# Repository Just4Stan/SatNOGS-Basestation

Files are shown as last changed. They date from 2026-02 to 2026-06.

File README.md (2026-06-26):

# SatNOGS Basestation

Portable, SatNOGS-compatible ground station for the **AetherSpace CubeSat** at 433 MHz.
Built as a joint Master's thesis at KU Leuven (Campus Geel), 2025–2026.

<p align="center">
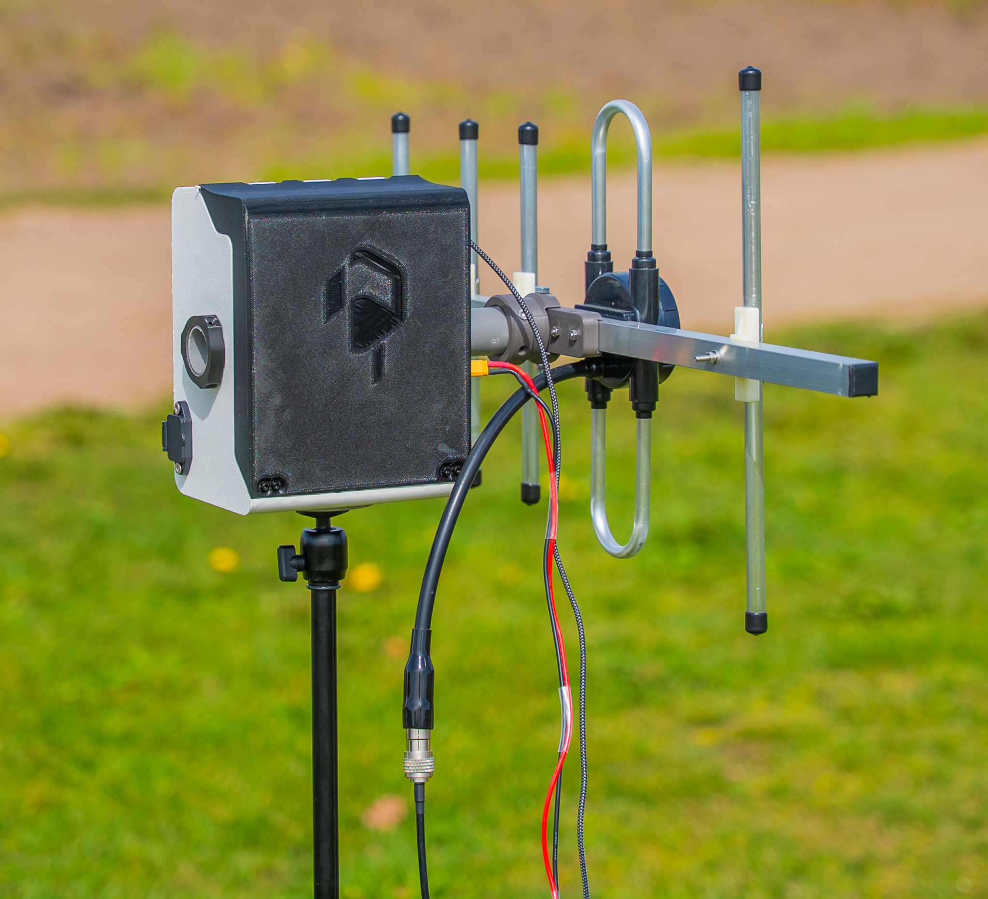
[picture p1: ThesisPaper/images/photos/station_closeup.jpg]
Station head with UHF Yagi
  
</p>
<p align="center">
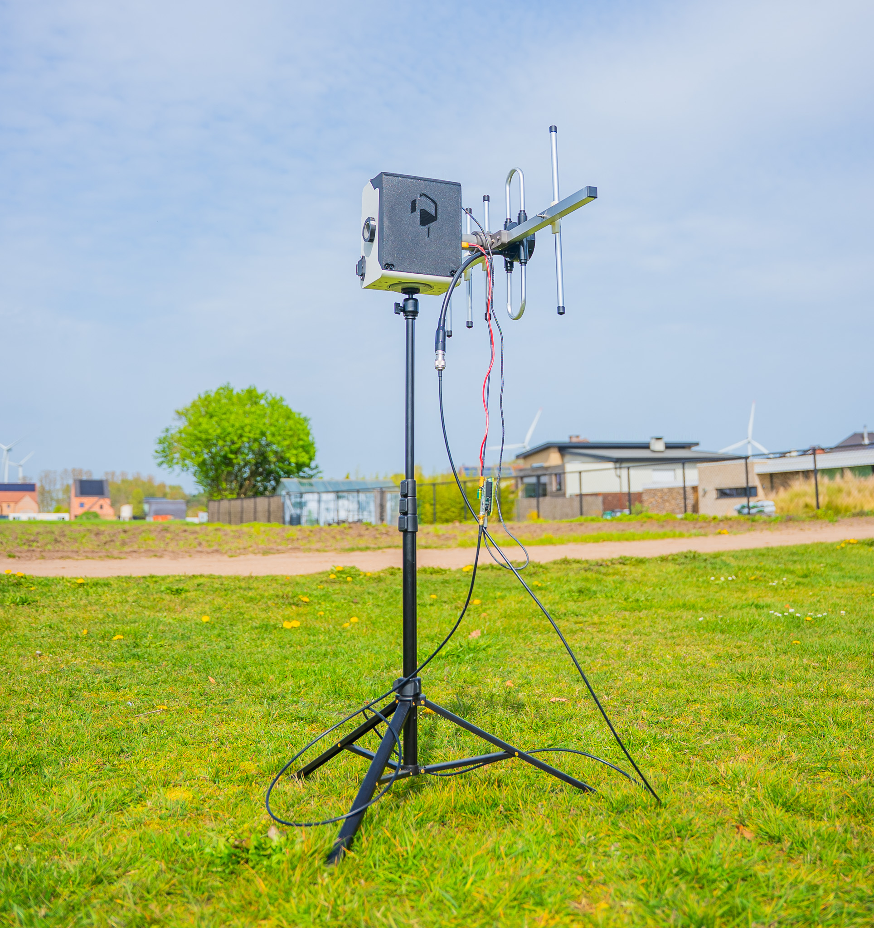
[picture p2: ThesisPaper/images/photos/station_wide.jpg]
Deployed on tripod in the field
  
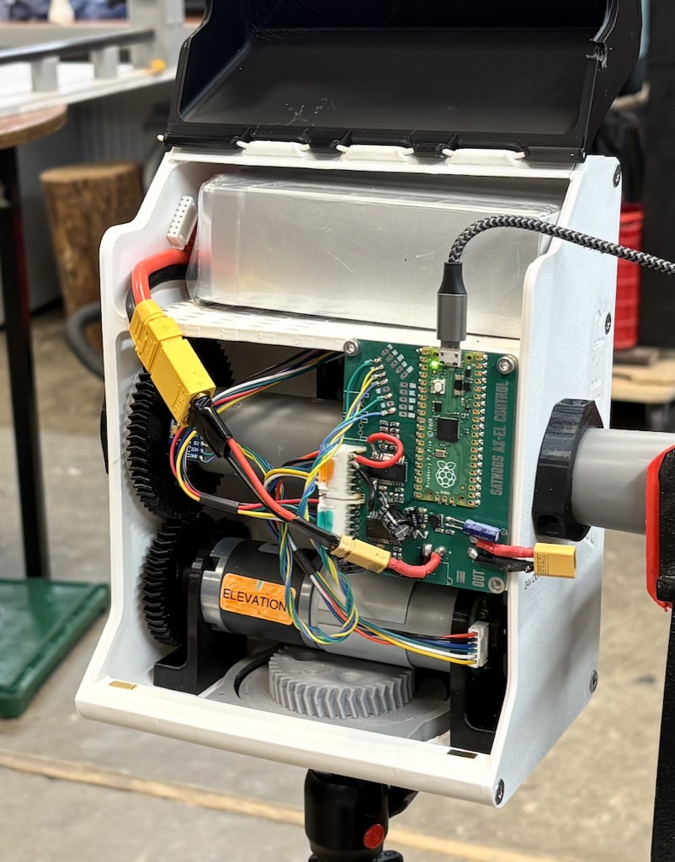
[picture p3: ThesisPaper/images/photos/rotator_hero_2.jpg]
Rotator internals — Pico, motor, herringbone gears
  
</p>

<p align="center">
  <b>3D-printable rotator</b> · <b>1/4"-20 tripod mount</b> · <b>EasyComm / hamlib compatible</b> · <b>phone-configured, no laptop</b>
</p>

---

## What this is (and what it isn't)

This project is a **deliberate alternative** to the canonical SatNOGS receive stack. A fully capable SatNOGS ground station can be built with a Raspberry Pi 3, the official `satnogs-client`, an RTL-SDR dongle, and any hamlib-compatible rotator — and for receiving arbitrary amateur satellites that is the right choice. We built this station instead because:

1. **AetherSpace-specific.** The AetherSpace CubeSat carries a TI CC1200 transceiver. Using the same CC1200 on the ground guarantees modulation-format compatibility and avoids the software-demodulator complexity of matching a CubeSat's exact FSK parameters in GNU Radio.
2. **Educationally interesting.** The build spans mechanical design (3D-printed rotator, printed ball bearings, herringbone gears), PCB design (dual-RP2040 + CC1200 HAT), embedded firmware (EasyComm III, PID, encoder ISRs, COBS protocol, PIO-based AX.25 G3RUH decoder), Pi-side software (pass prediction, Doppler, phone-first HTTPS dashboard), and protocol integration (SiDS to the SatNOGS DB). An SDR-based station would skip most of that.
3. **Portable and self-contained.** Deploys in minutes on a tripod, configured from a phone — no laptop, no SSH. This is harder with the GNU Radio-based `satnogs-client` which expects a persistent host.

If you want a general-purpose SatNOGS station today, run **`satnogs-client` + RTL-SDR on a Pi 3B+** with any EasyComm-speaking rotator (including this one). If you want to track AetherSpace or learn how a ground station is built end-to-end, use this.

---

## System overview

<p align="center">
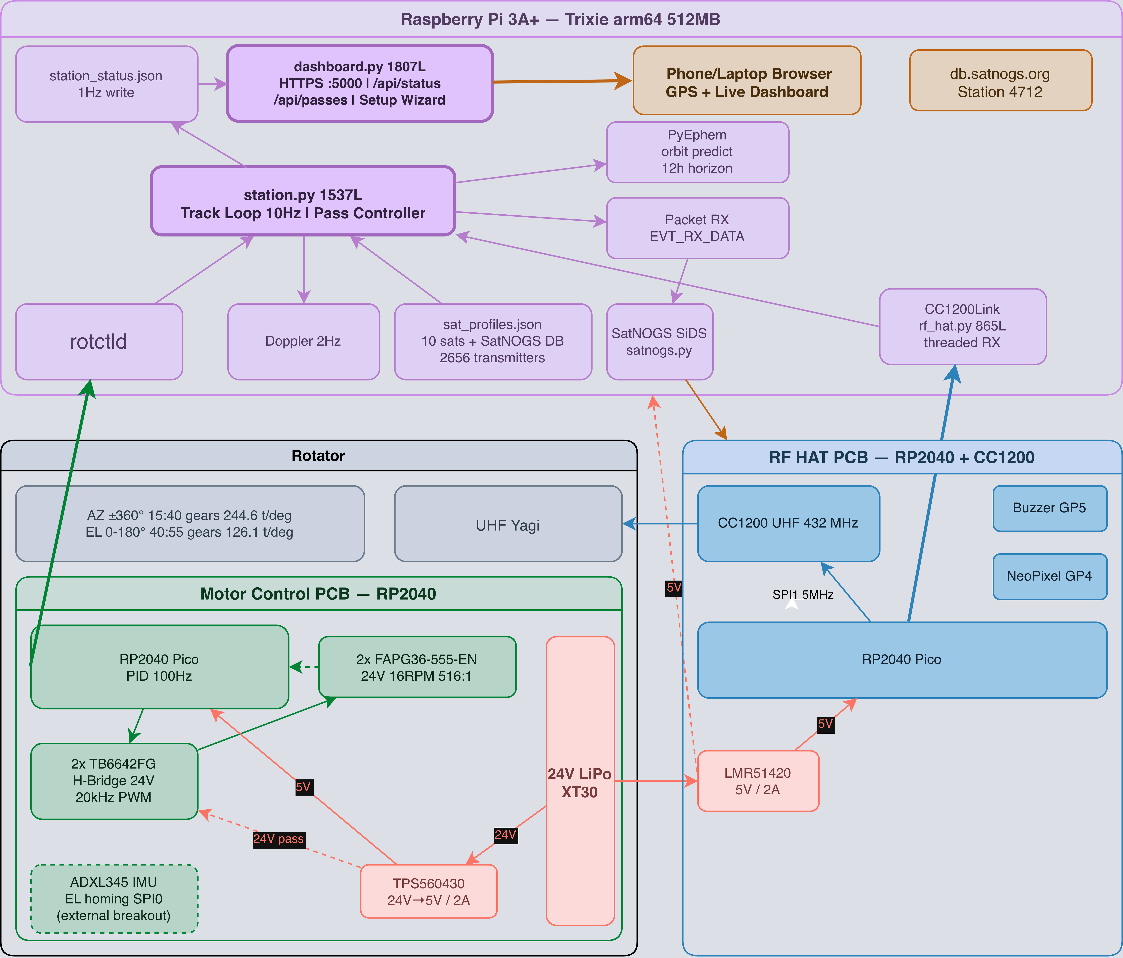
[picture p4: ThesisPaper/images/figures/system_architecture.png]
System architecture: Pi 3A+ driving the motor-control PCB and CC1200 RF HAT
  
</p>

> **v1** (above) is the field-validated configuration — two separate boards, USB for the rotator, UART for the RF HAT.
> **v2** (`MOTOR_RF_HAT/`) is the design-complete successor — one Pi HAT, A4950 motor drivers, 100 Ω GPIO series resistors on the driver lines. Routed and BOM-finalised; not yet fabricated.

---

## Repository structure

| Path | Contents |
|---|---|
| [`Firmware/rp2040-satnogs-rotator/`](Firmware/rp2040-satnogs-rotator/) | Rotator Pico firmware — EasyComm III, 100 Hz PID, IMU-based EL homing, runaway detection, watchdog |
| [`Firmware/rp2040-rf-hat/`](Firmware/rp2040-rf-hat/) | RF HAT Pico firmware — COBS/CRC-16 protocol, dual CC1200 SPI driver, PIO serial-mode RX + AX.25 G3RUH decoder |
| [`MotorPCB/`](MotorPCB/) | v1 KiCad 9 rotator controller PCB (13 hierarchical sub-sheets). Field-deployed. |
| [`RF_HAT/`](RF_HAT/) | v1 dual-CC1200 Pi HAT (source: `rf_hat_circuit.py` → generates `RF_HAT_out/`). Field-deployed. |
| [`MOTOR_RF_HAT/`](MOTOR_RF_HAT/) | v2 combined motor-control + RF HAT (design-complete, routed, ready to order). Thesis-final hardware. |
| [`Pi/`](Pi/) | Python station stack: `station.py`, `dashboard.py`, `rf_hat.py`, `sat_library.py`, decoders, systemd services, SmartRF configs |
| [`Hardware/`](Hardware/) | Motor + driver datasheets (FAPG36-555-EN, TB6642FG) |
| [`ThesisPaper/images/`](ThesisPaper/images/) | All thesis visuals: `figures/` (plots), `figures/evidence/` (reception evidence plots), `photos/` (hardware + CAD) — consumed by LaTeX `\graphicspath{./images/}` |
| [`ThesisPaper/`](ThesisPaper/) | LaTeX thesis (KU Leuven FIIW template) + rendered figures |
| [`tools/`](tools/) | Analysis utilities (`analyze_passes.py` — generates the reception-evidence report) |
| [`RF_Devboard/`](RF_Devboard/) | CC1200 RF dev board (predecessor to the HAT): Altium PCB, Pico SDK driver, PC test GUI |
| [`docs/`](docs/) | System architecture diagram (`.drawio` + HTML render) |
| `captures/` | Raw RF captures per pass (gitignored — kept on disk only) |
| `Papers/` | Reference material including Hanssens (2023) baseline thesis (gitignored) |

| Firmware artifact (at repo root) | Built by |
|---|---|
| `firmware.uf2` | `Firmware/rp2040-satnogs-rotator/` (v1 rotator) |
| `rf_hat_firmware.uf2` | `Firmware/rp2040-rf-hat/` (v1 RF HAT) |
| `motor_rf_hat_firmware.uf2` | `Firmware/rp2040-motor-rf-hat/` (v2 combined) |

---

## Hardware

<p align="center">
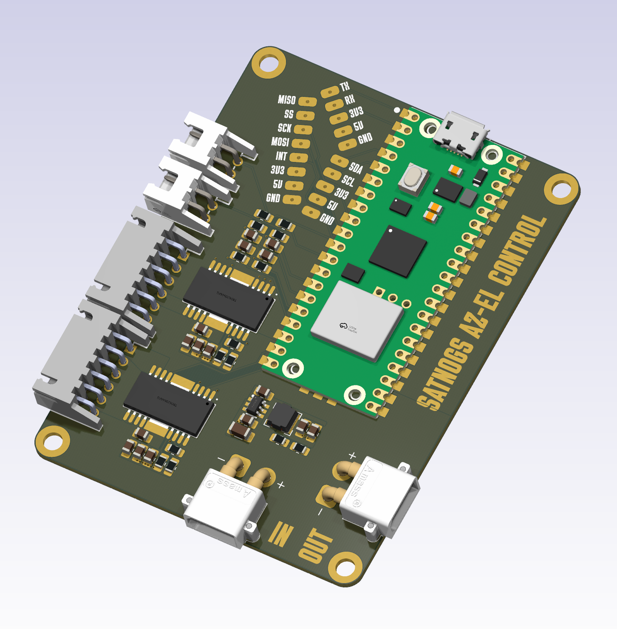
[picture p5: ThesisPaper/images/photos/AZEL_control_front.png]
v1 motor-control PCB
  
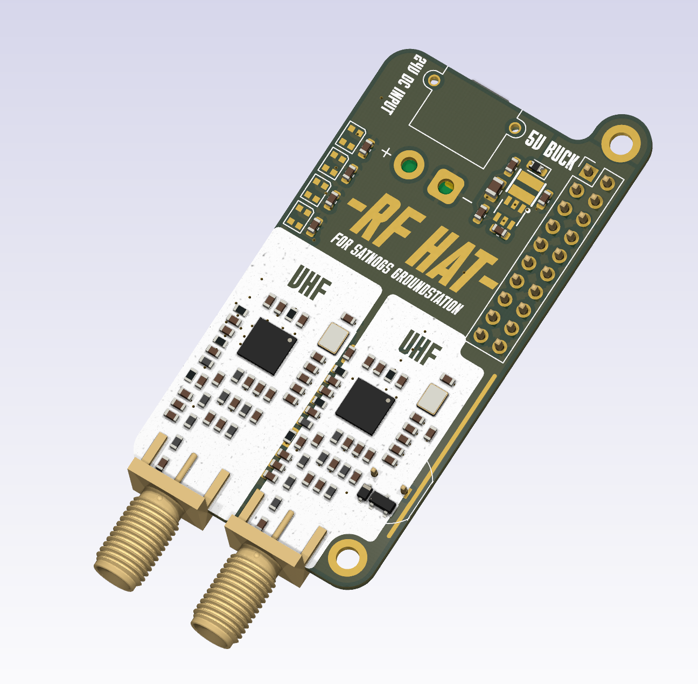
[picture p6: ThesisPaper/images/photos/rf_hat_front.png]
v1 dual-CC1200 RF HAT
  
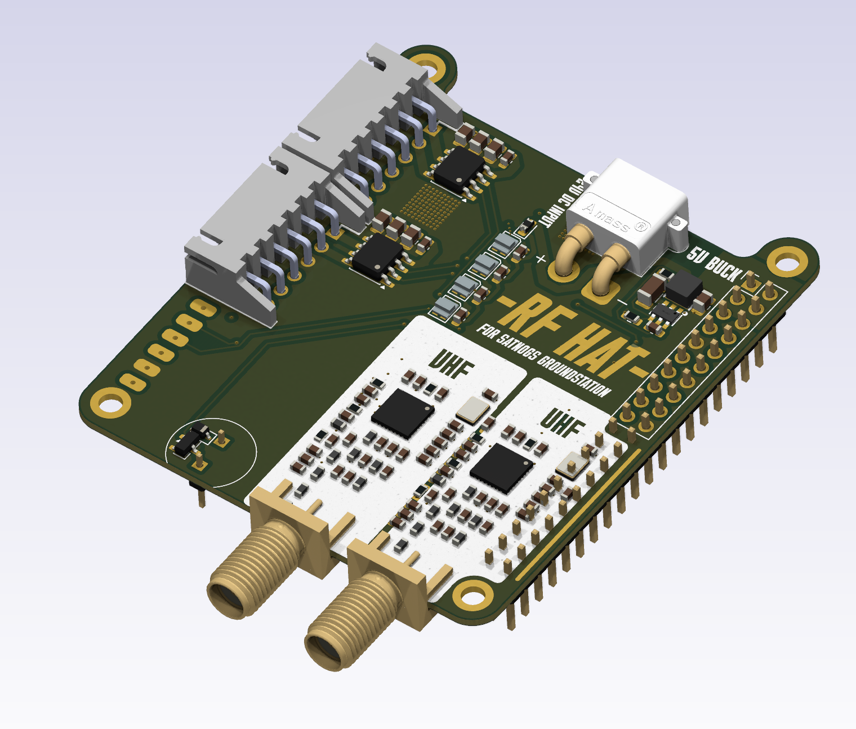
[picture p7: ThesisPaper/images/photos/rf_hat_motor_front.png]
v2 combined MOTOR_RF_HAT
  
</p>
<p align="center"><sub>Left to right: v1 motor-control PCB · v1 dual-CC1200 RF HAT · v2 combined MOTOR_RF_HAT (design-complete)</sub></p>

| Component | Details |
|---|---|
| **MCU** | RP2040 (Raspberry Pi Pico), one per board (v1); single RP2040 on v2 |
| **Motor driver (v1)** | 2× TB6642FG full-bridge (24 V, 20 kHz PWM) |
| **Motor driver (v2)** | 2× A4950 (standard, in-stock; replaces scarce TB6642FG) |
| **Motors** | FAPG36-555-EN, 24 V, 16 RPM, 516:1 internal planetary gearbox |
| **Encoders** | 2-channel Hall (64 edges/rev, 4× quadrature) |
| **IMU** | ADXL345 3-axis accelerometer (EL auto-homing at boot) |
| **RF** | 2× TI CC1200 on 6-layer Pi HAT — UHF (432 MHz) populated, VHF (144 MHz) routed only |
| **Antenna** | Siretta Oscar 44 Yagi, 434 MHz, ~9 dBi (used in field testing) over 3 m RG-58 |
| **Station computer** | Raspberry Pi 3 Model A+, Debian 13 (Trixie), armhf 32-bit |

### Axis gearing

| Axis | External ratio | Total ratio | Ticks/degree | Travel |
|---|---|---|---|---|
| Azimuth | 15:40 (2.667:1) | 1376:1 | 244.6 | ±360° |
| Elevation | 40:55 (1.375:1) | 709.5:1 | 126.1 | 0–180° |

No slip ring — AZ rewinds between passes via `PARK`. Shortest-path wrapping handles north crossings automatically.

### Mechanical design

<p align="center">
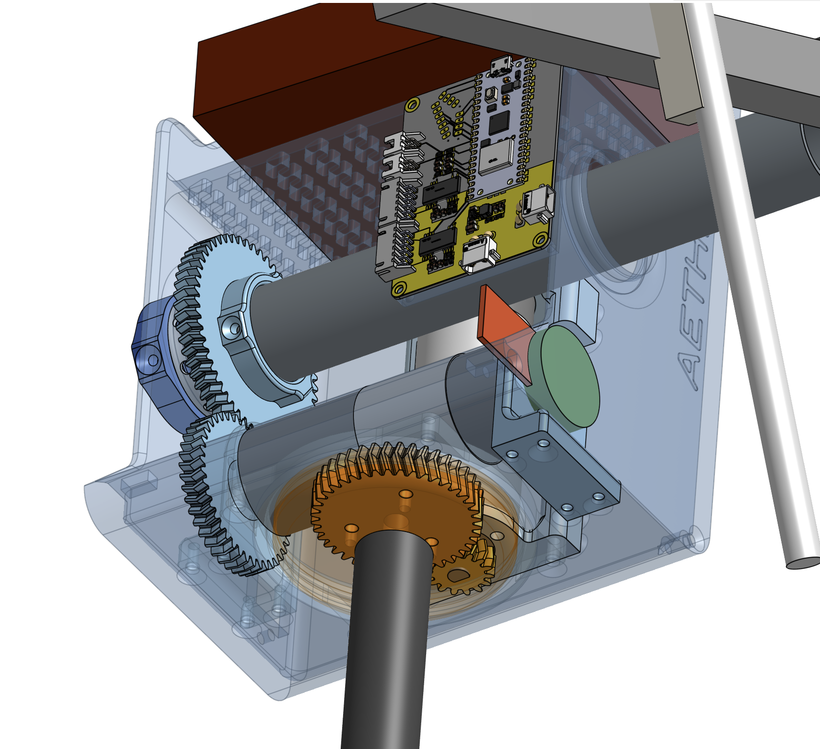
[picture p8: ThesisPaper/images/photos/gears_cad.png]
EL-axis CAD cutaway: herringbone gear train and Pico
  
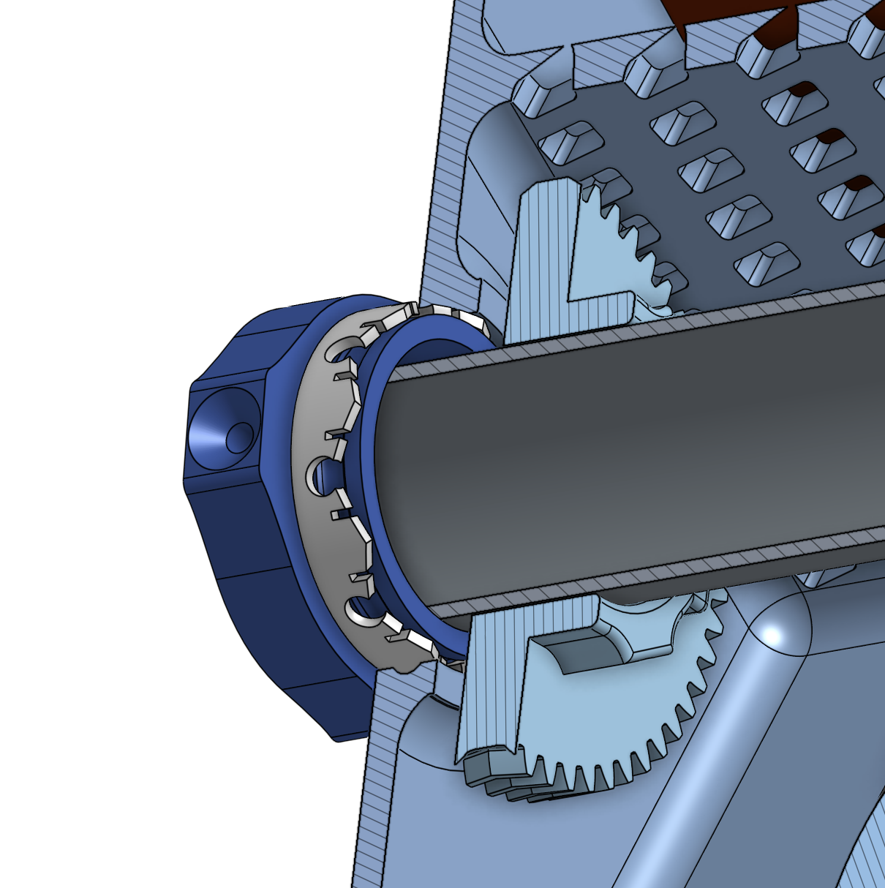
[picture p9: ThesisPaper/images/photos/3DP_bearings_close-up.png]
Printed deep-groove ball bearing
  
</p>

Fully 3D-printable in ASA (UV-resistant, Tg ≈ 100 °C). All structural parts fit a 220×220 mm build plate. Printed deep-groove ball bearings on both axes (3 mm steel balls, integrated races, press-in retainer). Double-helical (herringbone) gears, 15° helix, 1.333 mm normal module, 8 mm face width. Standard **1/4"-20 UNC tripod thread** on the base.

[View CAD on Onshape](https://cad.onshape.com/documents/a73149deb7dec0be4e4b4c14/w/e82e548d7d93085f89291bd5/e/c3e50364326e22d368cc64e2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)

---

## LNA recommendation (RX sensitivity)

Field testing without an external LNA produced **no protocol-valid frame decodes** — the link budget (`ThesisPaper/draft_link_budget.md`) shows the measured system noise floor sits roughly 20 dB above thermal, and the AetherSpace 14 dBm / 2 dBi downlink has insufficient margin at ~600 km range in that configuration. Adding an LNA is the single highest-impact upgrade.

**Recommended path — mast-mounted LNA + bias-T:**

| Part | Role | Notes |
|---|---|---|
| **Qorvo SPF5189Z** (or pre-built module, e.g. Nooelec SAWbird+ 433) | Primary LNA | NF 0.6 dB, ~20 dB gain at 433 MHz, SOT-89, +5 V, community standard for 433 MHz amateur RX |
| **Mini-Circuits PGA-103+** | Alternative | NF 0.5 dB, 21 dB gain, SMA module, more expensive |
| **EPCOS B39431B3710U410** (or equivalent) | 433.92 MHz SAW filter, pre-LNA | Rejects out-of-band interferers; improves linearity |
| Bias-T (on-PCB) | Feeds DC up the coax to power mast LNA | ~120 nH choke + DC-block capacitor + feedthrough |

**Why mast-mounted is preferred over PCB-integrated (Friis cascade):** the first stage's noise figure dominates the whole chain. Placing the LNA at the antenna bypasses ~0.6 dB of RG-58 loss *before* amplification, and avoids lifting board-level digital noise (RP2040, LMR51420 buck harmonics, Pi HDMI) into the RX path. A PCB-integrated LNA helps less for the same cost.

**TI CC1190 is not applicable here:** it is TI's companion range-extender for CCxxxx transceivers, but only covers 850–950 MHz. There is no TI-supplied LNA companion for CC1200 in the 410–475 MHz band, so an external discrete or module-based LNA is required.

The v2 MOTOR_RF_HAT should include a bias-T network on the UHF antenna port to make mast-LNA operation plug-and-play.

---

## Quick start

```sh
# Build rotator firmware
cd Firmware/rp2040-satnogs-rotator
pip install platformio
pio run
```

Flash: hold **BOOTSEL**, plug USB, copy `firmware.uf2` to the **RPI-RP2** drive.

Connect at 115200 baud (`pio device monitor` or any serial terminal):

```
AZ90.0 EL45.0    → move to position
AZ               → query current AZ/EL
STOP             → halt motors
PARK             → return to (0, 0)
VE               → firmware version
HELP             → list all commands
```

Full command reference and PID tuning: [`Firmware/rp2040-satnogs-rotator/README.md`](Firmware/rp2040-satnogs-rotator/README.md).

---

## SatNOGS integration

The rotator speaks **EasyComm III (hamlib model 204)** on the rotator path, so the Pi runs stock `rotctld` with no custom software. `rotctld.service` in [`Pi/services/`](Pi/services/) is the auto-start unit.

```sh
# rotctld exposes the rotator on TCP 4533
echo "p"             | nc <pi-ip> 4533   # query position
echo "P 90.0 30.0"   | nc <pi-ip> 4533   # command AZ 90, EL 30
```

### Satellite tracking

`Pi/station.py` predicts passes from CelesTrak TLEs via PyEphem, drives `rotctld` at 10 Hz, configures the CC1200 per satellite, applies Doppler correction at 2 Hz, and logs pass CSVs with 5 Hz telemetry.

```sh
cd ~/SatNOGS-Basestation/Pi
python3 station.py --list              # list upcoming passes
python3 station.py --sat "ISS"         # track a named satellite
python3 station.py --daemon            # auto-track all passes (no SSH)
```

See [`Pi/README.md`](Pi/README.md) for daemon mode, scan mode, and dashboard operation.

### SatNOGS DB (SiDS) vs `satnogs-client`

Decoded frames are submitted directly to `db.satnogs.org/api/telemetry/` via the SiDS (Simple Downlink Sharing) protocol. Station **4712 "Aether-Basestation"** is registered on the network; it will appear *offline* on the network map because we do not poll `/api/jobs/` — `satnogs-client`'s GNU Radio + SoapySDR pipeline is SDR-centric and incompatible with the CC1200 hardware packet modem.

**If you want the standard SatNOGS experience on top of this rotator:** install `satnogs-client` with any RTL-SDR dongle, set `SATNOGS_ROT_MODEL=ROT_MODEL_NETROTCTL` and `SATNOGS_ROT_PORT=localhost:4533`. The `RfBackend` abstraction in [`Pi/rf_backend.py`](Pi/rf_backend.py) also supports an RTL-SDR as a parallel path alongside the CC1200.

---

## Motion control

The rotator runs a 100 Hz PID loop per axis (Kp 0.15, Ki 0.03, Kd 0.02, 0.05° deadband, 95 % duty cap). The integral and derivative terms trade overshoot against settling time:

<p align="center">
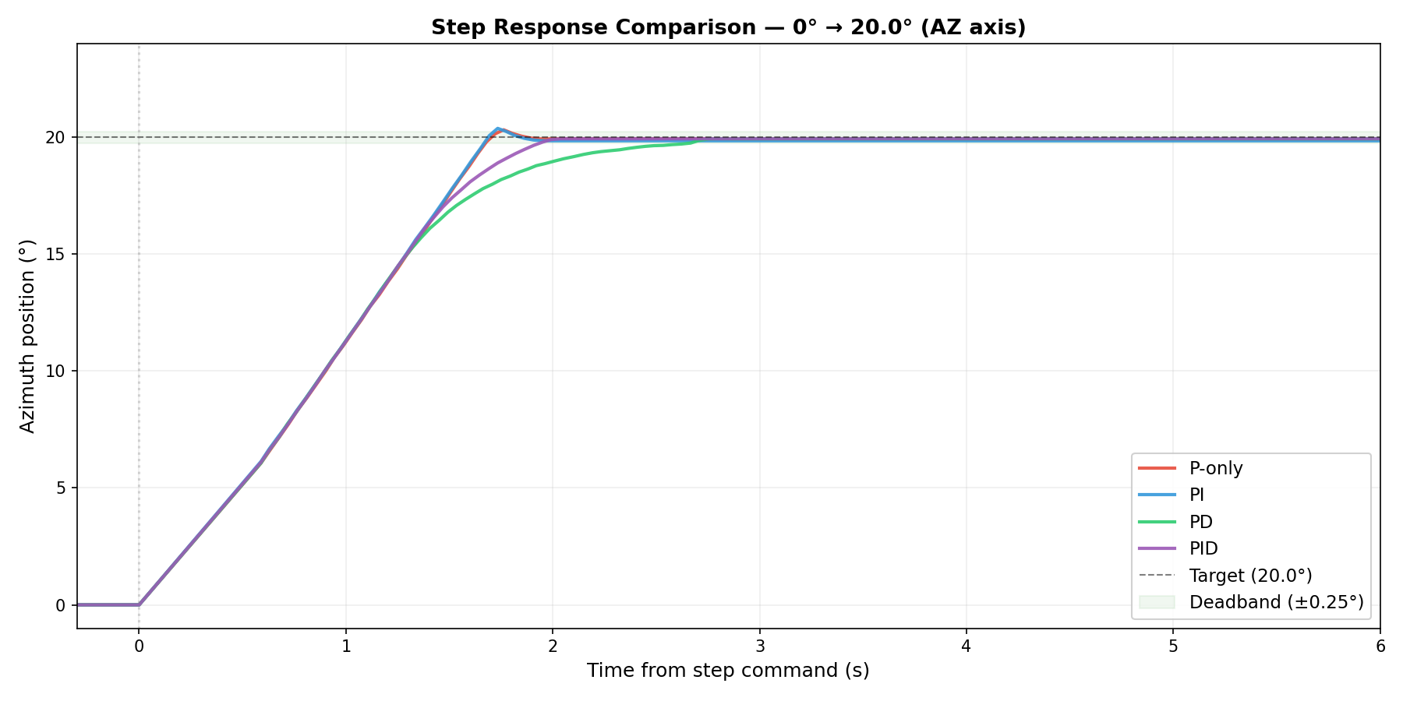
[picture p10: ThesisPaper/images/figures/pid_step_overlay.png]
AZ-axis step response: P, PI, PD and PID compared
  
</p>

---

## Safety features

- **Runaway detection** — emergency stop if position exceeds soft limits by 50° (catches PID positive-feedback failures like the EL-inversion bug found during bring-up)
- **Soft limits** — AZ clamped to ±360°, EL clamped to 0–180°
- **Duty capping** — 95 % max PWM, avoids TB6642FG/A4950 over-current on motor stall
- **IMU-based EL homing** — drives EL to horizontal via ADXL345 gravity vector at boot
- **Shortest-path AZ wrapping** — 350°→10° takes the 20° path, not 340°; encoder re-centres after settling near ±360°
- **8 s hardware watchdog** — both Picos; includes homing loop
- **Driver fault lines** — TB6642FG ALERT pins wired to the RP2040 (currently bypassed in firmware; enable for v2)

---

## Design philosophy

- **Economical.** v2 rotator BOM (controller board + motors + mechanics) ≈ €75; ≈ €100 including the Pi.
- **Reproducible.** 3D-printable rotator on a consumer FDM printer, standard 1/4"-20 tripod, LCSC-basic components where possible.
- **Stock-protocol.** EasyComm + hamlib on the rotator; SiDS on the DB side. No proprietary glue.
- **Open source.** Hardware CERN-OHL-S, firmware and software MIT.

---

## Further reading

- [`ThesisPaper/`](ThesisPaper/) — full LaTeX thesis (KU Leuven FIIW template) and figures.
- [`ThesisPaper/draft_link_budget.md`](ThesisPaper/draft_link_budget.md) — link-budget analysis with LNA impact.
- [`docs/system_architecture.drawio`](docs/system_architecture.drawio) — editable system diagram (`docs/system_diagram.html` renders it).
- Per-board READMEs under [`Firmware/`](Firmware/), [`Pi/`](Pi/), [`MotorPCB/`](MotorPCB/), [`RF_HAT/`](RF_HAT/), and [`MOTOR_RF_HAT/`](MOTOR_RF_HAT/).

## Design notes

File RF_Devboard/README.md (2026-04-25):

# CC1200RXFrontend

Firmware for an RP2040-based CC1200 “RF frontend” that controls a TI **CC1200** sub-GHz transceiver and exposes a **binary protocol over USB CDC**. The intended use case is a **SatNOGS groundstation** host that configures the CC1200, switches RX/TX state, monitors metrics, ingests received bytes (either polled or streamed), and can perform basic **TX test transmissions**.

Key features:
- USB CDC **binary protocol** (COBS framing + CRC16) for control, telemetry, optional RX streaming, and basic TX commands
- CC1200 SPI driver supporting normal + extended registers, FIFO reads/writes, and command strobes
- Host reference implementation and GUI in `PC_test/cc1200_gui.py` (includes a **Send Hex** TX test)
- RP2040 LED status indication

> Critical constraint: USB CDC stdio is used for the binary protocol. Printing debug text over the same interface will corrupt the stream.

---

## Repository layout

- `src/main.c`  
  System init, CC1200 bring-up, protocol polling loop.

- `src/usb_proto.[ch]`  
  Binary protocol framing/parsing and command dispatch. Handles RX streaming, metrics collection, and TX FIFO / TX start commands.

- `src/usb_cobs.[ch]`  
  COBS encoder/decoder used by the transport.

- `src/crc16.[ch]`  
  CRC-16/CCITT-FALSE implementation used by the transport.

- `src/config.h`  
  RP2040 pin mapping + SPI configuration.

- `src/leds.[ch]`  
  RGB status LED control and heartbeat.

- `CC1200_driver/cc1200.[ch]`  
  CC1200 low-level driver: register access, FIFO access, strobes.

- `CC1200_driver/cc1200_hal.[ch]`  
  Pico SDK SPI/GPIO HAL for CC1200. Includes SO(MISO)-ready wait on CS assert.

- `src/cc1200_profile.c`  
  Helper for applying a prepared list of register writes.

- `PC_test/cc1200_gui.py`  
  Reference host-side implementation and GUI (serial framing/parsing, SmartRF export parsing, register I/O, state control, RX ingest, **TX “Send Hex” test**).

---

## Hardware assumptions

### Default RP2040 pin mapping

Defined in `src/config.h`:

**LEDs**
- `GPIO12` : Blue
- `GPIO13` : Green
- `GPIO14` : Red
- `GPIO15` : Extra / heartbeat

**CC1200 (SPI0)**
- `GPIO18` : SCK
- `GPIO19` : MOSI
- `GPIO20` : MISO (also used for SO-ready)
- `GPIO21` : CSN
- `GPIO22` : CC1200 GPIO0
- `GPIO23` : CC1200 GPIO2
- `GPIO24` : CC1200 GPIO3
- `GPIO25` : CC1200 RESET

SPI frequency defaults to **5 MHz**. SO-ready timeout defaults to **5000 µs**.

### SPI mode and SO-ready behavior

- SPI is configured for **Mode 0**, 8-bit, MSB-first.
- On CSN assert (low), the HAL waits for CC1200 **SO (wired to MISO)** to go low, with a timeout. If SO does not go ready, the transfer is aborted.

---

## Firmware lifecycle

At boot:
1. Initializes USB CDC stdio and LEDs.
2. Initializes CC1200 HAL (SPI + GPIO) from `config.h`.
3. Resets CC1200 and verifies communication.
4. Optionally reads CC1200 identification fields (part/version) to validate the transceiver.
5. Enters a polling loop:
   - toggles heartbeat
   - processes incoming USB frames and emits responses/events
   - (optionally) drains RX FIFO and emits RX streaming events
   - sleeps briefly

---

## USB CDC binary protocol

### Transport framing

Frames are transmitted as:
- `COBS(payload) + 0x00` delimiter

Payload layout (little-endian where applicable):
- `type`  : `u8`
- `seq`   : `u8`
- `len`   : `u16` length of `body`
- `body`  : `len` bytes
- `crc16` : `u16` CRC-16/CCITT-FALSE computed over `type..body` (header + body, excluding delimiter)

CRC parameters:
- Polynomial: `0x1021`
- Init: `0xFFFF`
- XOROUT: `0x0000`
- RefIn/RefOut: false (CCITT-FALSE)

### Message types

#### Control / status
- `0x01` `MSG_PING`
- `0x02` `MSG_GET_INFO`
- `0x03` `MSG_SET_STATE`
  - `STATE_IDLE = 0`
  - `STATE_RX   = 1`
  - `STATE_TX   = 2` *(TX strobe; mainly useful for quick testing)*
- `0x04` `MSG_SET_STREAMING` (enable/disable async RX events)
- `0x05` `MSG_GET_METRICS`

#### Register I/O
- `0x10` `MSG_READ_REG`
- `0x11` `MSG_WRITE_REG`
- `0x12` `MSG_READ_EXT`
- `0x13` `MSG_WRITE_EXT`

#### FIFO / strobes
- `0x20` `MSG_RX_READ` (pull-mode RX FIFO read)
- `0x21` `MSG_STROBE`

#### TX (FIFO + transmit)
These commands provide a minimal TX path suitable for basic test transmissions. Actual on-air formatting depends on the active CC1200 packet configuration (SmartRF profile).

- `0x24` `MSG_TX_FLUSH`  
  Flush TX FIFO (`SFTX`).

  Request body: *(empty)*  
  Response body:
  - `ok` : `u8` (1 on success)

- `0x22` `MSG_TX_WRITE`  
  Write bytes into TX FIFO.

  Request body:
  - `flags` : `u8`
    - bit0: flush TX FIFO before writing (`SFTX`)
    - bit1: force IDLE before touching TX path (`SIDLE`)
  - `count` : `u8`
  - `data`  : `count` bytes

  Response body:
  - `ok`      : `u8` (1 on success)
  - `written` : `u8` (bytes written)

- `0x23` `MSG_TX_SEND`  
  Trigger transmit (`STX`) after data is staged in TX FIFO.

  Request body:
  - `flags` : `u8` *(optional; if omitted, defaults to 0)*
    - bit0: strobe `SIDLE` after `STX`
    - bit1: strobe `SRX` after `STX` (RX wins if both bit0+bit1 set)
    - bit2: flush TX FIFO before `STX` (`SFTX`) *(mostly useful for “empty send” sanity tests)*

  Response body:
  - `ok` : `u8` (1 on success)

> Note: These TX commands are “raw FIFO + STX”. If your profile uses the CC1200 packet engine with a length byte, CRC, whitening, etc., the bytes you write must match what the configured packet engine expects.

#### Profile staging (bulk apply)
- `0x30` `MSG_PROFILE_CLEAR`
- `0x31` `MSG_PROFILE_BEGIN`
- `0x32` `MSG_PROFILE_CHUNK`
- `0x33` `MSG_PROFILE_APPLY`

#### Responses and events
- Responses set `type |= 0x80` (response flag) and mirror the request `seq`.
- Async events:
  - `0xE0` `EVT_RX_DATA`
  - `0xE1` `EVT_ERROR`
  Async events typically use `seq = 0`.

### Error handling

- Malformed frames and CRC failures emit `EVT_ERROR`.
- Command-level errors (invalid args, SPI failures, bounds issues, overflow conditions) also emit `EVT_ERROR`.

---

## CC1200 control and data path

### Driver capabilities

The CC1200 driver supports:
- Normal register read/write
- Burst access
- Extended register access via the CC1200 “extended address” mechanism
- RX/TX FIFO burst reads/writes
- Command strobes (e.g., `SIDLE`, `SRX`, `SFRX`, `SFTX`, `STX`)

### RX streaming (push mode)

When streaming is enabled with `MSG_SET_STREAMING`:
- Firmware polls the CC1200 RX FIFO byte count and drains available bytes in chunks (up to 64 bytes per event).
- Each chunk is emitted as `EVT_RX_DATA`.

`EVT_RX_DATA` body format:
- `count` : `u8`
- `data`  : `count` bytes

This is the preferred ingestion mode for a groundstation pipeline that continuously forwards RX bytes to a demod/decoder stage.

### Pull-mode RX FIFO read

`MSG_RX_READ` requests a read of up to `max_bytes` from RX FIFO and returns:

Response body:
- `count` : `u8`
- `data`  : `count` bytes

### TX test path (raw FIFO + STX)

A basic TX sequence is:
1. `MSG_TX_FLUSH` *(optional but recommended for tests)*
2. `MSG_TX_WRITE` with `flags.bit0=1` to flush and `flags.bit1=1` to force `SIDLE`
3. `MSG_TX_SEND` to strobe `STX` (optionally return to `IDLE` or `RX` after)

The reference GUI includes a **TX Test (Send Hex)** panel that performs exactly this sequence.

---

## Metrics

`MSG_GET_METRICS` reads CC1200 status values and returns a compact metrics block, including:
- MARC state
- RX FIFO byte count
- RSSI (reconstructed from CC1200 RSSI registers)

Returned body (current format):
- `marc`        : `u8`
- `rxbytes`     : `u8` (masked to 7 bits by firmware)
- `rssi_raw_1db`: `i8` (coarse display value)
- `rssi_dbm_x10`: `i16` (dBm * 10, little-endian; `-32768` indicates invalid)

The Python GUI supports both legacy (short) and current (extended) metrics response formats.

---

## Profile configuration (SmartRF exports)

Two mechanisms exist:

1. **Direct register writes**  
   The host writes registers (normal and extended) one-by-one using `MSG_WRITE_REG` / `MSG_WRITE_EXT`.
   This is implemented in the reference GUI and is straightforward but more transaction-heavy.

2. **Bulk staging and apply** (recommended for SatNOGS integration)  
   The host stages register operations in RAM and applies them in one commit:
   - `MSG_PROFILE_CLEAR` clears staged entries
   - `MSG_PROFILE_BEGIN` starts a staging session (optional expected count)
   - `MSG_PROFILE_CHUNK` appends entries
   - `MSG_PROFILE_APPLY` writes all staged entries (firmware strobes `SIDLE` first)

`MSG_PROFILE_CHUNK` body format:
- `count` : `u8`
- Repeated `count` times:
  - `type` : `u8` (bit0 = 1 means extended register write, 0 means normal)
  - `addr` : `u8`
  - `val`  : `u8`

`MSG_PROFILE_APPLY` may accept an apply-flags byte to strobe after writing:
- bit0: strobe `SRX`
- bit1: strobe `SIDLE`
- bit2: strobe `SFRX`
- bit3: strobe `SFTX`

---

## Building (Pico SDK)

### Dependencies
- Raspberry Pi Pico SDK (PICO_SDK_PATH must be set)
- CMake
- Ninja (optional but used by example)

### Example build (Windows)

```bat
cd C:\pico\satnogs_rx_frontend
rmdir /s /q build
mkdir build
cd build

set PICO_SDK_PATH=C:\pico\pico-sdk

cmake -G "Ninja" ..
cmake --build .

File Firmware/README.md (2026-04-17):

# Firmware — SatNOGS Ground Station Software System

Two RP2040 Pico microcontrollers, controlled by a single Raspberry Pi 3 Model A+,
form the ground station electronics:

```
                          ┌─────────────────────────────────────────────────────┐
                          │  Raspberry Pi 3 Model A+                            │
                          │  (Debian 13 Trixie, armhf 32-bit)                   │
                          │                                                     │
                          │  ┌──────────────┐   ┌────────────────────────────┐  │
                          │  │ rotctld      │   │ Python packet capture      │  │
                          │  │ model 204    │   │ (COBS/UART protocol)       │  │
                          │  │ port 4533    │   │                            │  │
                          │  └──────┬───────┘   └────────────┬───────────────┘  │
                          │         │                        │                  │
                          │    USB serial              UART (GPIO14/15)         │
                          │    /dev/ttyACM0            115200 baud              │
                          └─────────┼────────────────────────┼──────────────────┘
                                    │                        │
                          ┌─────────┴─────────┐    ┌─────────┴─────────────────┐
                          │  Rotator Pico     │    │  RF HAT Pico              │
                          │  (Motor Control)  │    │  (CC1200 Controller)      │
                          │                   │    │                           │
                          │  USB CDC serial   │    │  UART0 (GP0/GP1)          │
                          │  EasyComm protocol│    │  COBS binary protocol     │
                          │                   │    │                           │
                          │  ┌──────┐ ┌──────┐│    │  ┌───────┐  ┌───────┐     │
                          │  │AZ mot│ │EL mot││    │  │CC1200 │  │CC1200 │     │
                          │  │TB6642│ │TB6642││    │  │UHF    │  │VHF    │     │
                          │  │IN1/2 │ │IN1/2 ││    │  │432 MHz│  │144 MHz│     │
                          │  │+PWM  │ │+PWM  ││    │  │SPI1   │  │SPI0   │     │
                          │  └──────┘ └──────┘│    │  └───────┘  └───────┘     │
                          │  ┌──────┐ ┌──────┐│    │                           │
                          │  │AZ enc│ │EL enc││    │  ┌───────┐  ┌───────┐     │
                          │  │quad  │ │quad  ││    │  │UHF    │  │VHF    │     │
                          │  │IRQ   │ │IRQ   ││    │  │SMA    │  │SMA    │     │
                          │  └──────┘ └──────┘│    │  │antenna│  │antenna│     │
                          │  ┌──────┐ ┌──────┐│    │  └───────┘  └───────┘     │
                          │  │ADXL  │ │end-  ││    │                           │
                          │  │345   │ │stops ││    │                           │
                          │  │SPI0  │ │GPIO  ││    │                           │
                          │  └──────┘ └──────┘│    │                           │
                          └───────────────────┘    └───────────────────────────┘
```

## How the System Works

### 1. Rotator (antenna pointing)

The **Rotator Pico** sits on the Motor Control PCB (`MotorPCB/`) and drives two FAPG36-555-EN
gear motors (24V, 516:1 internal gearbox) through TB6642FG H-bridge drivers. Quadrature encoders
on each axis provide position feedback. An ADXL345 accelerometer on SPI0 gives absolute elevation
at boot from the gravity vector.

The Pico speaks the **SatNOGS EasyComm** protocol over **USB CDC serial** at 115200 baud.
On the Pi, `rotctld` (hamlib model 204) connects to `/dev/ttyACM0` and exposes a TCP socket
(port 4533). `satnogs-client` (or any hamlib client) sends pointing commands via `rotctl`.

This path is fully stock SatNOGS — no custom Pi software is needed for rotator control.

**Key specs:**
- AZ: 244.6 encoder ticks/degree (64 CPR x 516:1 x 40/15 external)
- EL: 126.1 encoder ticks/degree (64 CPR x 516:1 x 55/40 external)
- PID control at 100 Hz (Kp=0.15, Ki=0.03, Kd=0.02)
- Slew speed: ~35 deg/s at 95% duty
- Soft limits: AZ +/-360 deg, EL 0-180 deg

### 2. RF Front-End (packet transceiver)

The **RF HAT Pico** sits on the RF HAT PCB (`RF_HAT/`) — a Pi 3A+ HAT carrying two TI CC1200
sub-GHz transceivers. The Pico controls both CC1200s over SPI and communicates with the Pi
over **UART** (GP0/GP1, 115200 baud, wired to Pi GPIO14/15).

This is the same architecture used by the M17 CC1200 HAT reference design (SP5WWP/DB9MAT).
The binary protocol uses **COBS framing** with **CRC-16/CCITT-FALSE** integrity checks.

The CC1200 is a hardware packet modem — it handles modulation/demodulation, sync word detection,
and CRC checking internally. It does **not** produce IQ samples like an SDR.

**Key specs:**
- UHF: 432 MHz CC1200 on SPI1 (GP10-13)
- VHF: 144 MHz CC1200 on SPI0 (GP16-19)
- Default config: 2-GFSK, ~2.4 kbps, ~5 kHz deviation, +14 dBm TX
- Dual-radio select via protocol (MSG_SELECT_RADIO)
- SmartRF Studio register profiles loaded at runtime

### 3. Pi Software Stack

The Raspberry Pi runs:

| Component | Purpose | Interface |
|---|---|---|
| `rotctld` | hamlib rotator daemon | USB serial → Rotator Pico |
| `station.py` | Pass prediction + tracking + CC1200 control (this project, not satnogs-client) | TCP → rotctld + UART → RF HAT Pico |
| `dashboard.py` | HTTPS phone-first field UI | Same status file as station.py |

**Data flow during a satellite pass:**

1. `station.py` (daemon mode) computes upcoming passes from CelesTrak TLEs via PyEphem.
2. `station.py` sends AZ/EL pointing commands via `rotctld` → Rotator Pico tracks the satellite at 10 Hz.
3. In parallel, `station.py`:
   - Selects the correct radio (UHF or VHF) via `MSG_SELECT_RADIO`
   - Loads the appropriate SmartRF register profile via `PROFILE_BEGIN` / `PROFILE_CHUNK` / `PROFILE_APPLY`
   - Enables RX streaming via `MSG_SET_STREAMING`
   - Reads incoming packets from `EVT_RX_DATA` events
   - Optionally applies Doppler correction by recalculating CC1200 frequency registers mid-pass
4. Decoded frames are submitted to [SatNOGS DB](https://db.satnogs.org/) via the SiDS API

### 4. SatNOGS Integration Notes

SatNOGS is SDR-centric (GNU Radio + SoapySDR flowgraphs). The CC1200 cannot plug into that
pipeline directly because it produces decoded packets, not raw IQ. Integration options:

1. **Recommended (current plan):** Run `satnogs-client` for scheduling and rotator control.
   Capture CC1200 packets independently via a Python script on the Pi. Submit decoded frames
   to SatNOGS DB via the SiDS API.

2. **Pre/post scripts:** Use satnogs-client observation hooks to start/stop CC1200 packet capture
   around scheduled passes automatically.

3. **Doppler correction:** Write a minimal `rigctld` shim that translates hamlib `set_freq` commands
   to CC1200 frequency register writes (FREQ2/FREQ1/FREQ0 in extended register space).

4. **Hybrid:** Add an RTL-SDR for standard SatNOGS waterfall/audio/IQ artifacts. Use the CC1200
   as the primary packet decoder (hardware demod is more reliable for narrow-band FSK).

## Project Structure

```
Firmware/
├── README.md                          ← this file
├── rp2040-satnogs-rotator/            ← Rotator Pico firmware (PlatformIO)
│   ├── platformio.ini
│   ├── copy_uf2.py
│   ├── README.md                      ← detailed rotator firmware docs
│   └── src/
│       ├── main.cpp                   Arduino entry point + main loop
│       ├── pins.h                     GPIO map (from MotorPCB netlist)
│       ├── config.h                   Calibration + PID + limits
│       ├── motor_pwm.cpp/h            TB6642FG PWM driver
│       ├── quadrature.cpp/h           Gray-code encoder decoder (IRQ)
│       ├── rotator.cpp/h              Closed-loop PID + homing + safety
│       ├── satnogs_protocol.cpp/h     EasyComm command parser
│       └── adxl345.cpp/h              ADXL345 accelerometer (SPI)
│
├── rp2040-rf-hat/                     ← RF HAT Pico firmware (PlatformIO) — v1, field-deployed
│   ├── platformio.ini
│   ├── copy_uf2.py
│   ├── README.md                      ← detailed RF HAT firmware docs
│   ├── lib/cc1200_driver/             CC1200 SPI driver + HAL
│   │   ├── cc1200.c/h                 Register/FIFO/strobe access
│   │   ├── cc1200_hal.c/h             RP2040 SPI + GPIO HAL
│   │   └── library.json
│   ├── src/
│   │   ├── main.cpp                   Arduino entry point + dual CC1200 init
│   │   ├── config.h                   Pin map + radio constants
│   │   ├── proto.c/h                  Binary protocol handler (COBS/UART)
│   │   ├── cobs.c/h                   COBS framing codec
│   │   ├── crc16.c/h                  CRC-16/CCITT-FALSE
│   │   ├── ax25_decode.c/h            AX.25 G3RUH software decoder (PIO serial mode)
│   │   └── serial_rx.pio.h            PIO program for synchronous bitstream capture
│   └── tools/
│       └── cc1200_regmap_profile.json Profile-applicable registers
│
└── rp2040-motor-rf-hat/               ← v2 combined firmware scaffold
                                       (target: MOTOR_RF_HAT combined board —
                                        design-complete, not yet fabricated).
                                       Pin plan + protocol are locked in
                                       config.h; when v2 boards arrive, re-merge
                                       the latest rotator + rf-hat sources on
                                       top of this scaffold. Not currently
                                       compiled or flashed.
```

## Build & Flash

Both projects use [PlatformIO](https://platformio.org/) with the Arduino-Pico (earlephilhower) core.
Raw Pico SDK APIs (hardware_pwm, hardware_spi, hardware_gpio, etc.) work alongside Arduino.

```bash
# Rotator Pico
cd Firmware/rp2040-satnogs-rotator
pio run                    # build → firmware.uf2 (copied to repo root)
pio run -t upload          # flash via BOOTSEL
pio device monitor         # USB serial console (115200 baud)

# RF HAT Pico
cd Firmware/rp2040-rf-hat
pio run                    # build → rf_hat_firmware.uf2 (copied to repo root)
pio run -t upload          # flash via BOOTSEL
pio device monitor         # USB debug serial (115200 baud)
```

**Flashing:** Hold BOOTSEL on the Pico, plug USB, release. The Pico appears as a USB drive
(`/Volumes/RPI-RP2`) — drag the `.uf2` file onto it. Alternatively, `pio run -t upload` uses
the 1200bps serial reset trick to enter bootloader automatically.

## Hardware

| Component | PCB | Specs |
|---|-----|---|
| AZ/EL motors | MotorPCB | FAPG36-555-EN, 24V, 516:1, 16 RPM |
| Motor drivers | MotorPCB | TB6642FG, IN1/IN2 + PWM mode |
| Quadrature encoders | MotorPCB | Built into motors, 64 CPR (16 PPR x 4x decode) |
| ADXL345 accelerometer | MotorPCB | SPI0, EL calibration from gravity |
| Endstop switches | MotorPCB | 1 per axis, active-low with pull-up |
| CC1200 UHF | RF HAT | 432 MHz, SPI1, 40 MHz crystal |
| CC1200 VHF | RF HAT | 144 MHz, SPI0, 40 MHz crystal |
| CC1200 power | RF HAT | 3.3V from Pico's onboard RT6150 regulator |

## Origin

The rotator firmware was developed from scratch for the Motor Control PCB.
The RF HAT firmware is based on [CC1200RXFrontend](https://github.com/RobbeLehaen/CC1200RXFrontend)
by Robbe Lehaen, adapted for dual-radio UART operation on the RF HAT hardware.

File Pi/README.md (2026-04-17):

# Raspberry Pi Setup — SatNOGS Ground Station

Complete setup guide for the Pi 3 Model A+ that runs the ground station.
The Pi talks to two RP2040 Picos simultaneously:

It should be compatible with any Raspberry Pi from the Pi3+ and beyond so Pi4, Pi5 and Pi Zero as of writing. This is untested

```
                  ┌───────────────────────────────────────────────────┐
                  │  Raspberry Pi 3 Model A+                          │
                  │  Bookworm arm64, IP 10.72.3.105                   │
                  │                                                   │
                  │  ┌────────────┐  ┌────────────┐  ┌────────────┐   │
                  │  │ rotctld    │  │ station.py │  │ satnogs-   │   │
                  │  │ (hamlib)   │  │ capture.py │  │ client     │   │
                  │  │ port 4533  │  │ transmit.py│  │ (optional) │   │
                  │  └─────┬──────┘  └─────┬──────┘  └─────┬──────┘   │
                  │        │               │               │          │
                  │   USB serial      Pi UART          TCP 4533       │
                  │  /dev/ttyACM0    /dev/serial0    → rotctld        │
                  └────────┼───────────────┼───────────────┘          │
                           │               │                          │
                  ┌────────┴────────┐ ┌────┴──────────────────┐       │
                  │  Rotator Pico   │ │  RF HAT Pico          │       │
                  │  EasyComm proto │ │  COBS binary proto    │       │
                  │  (USB CDC)      │ │  (UART 115200)        │       │
                  │                 │ │                       │       │
                  │  AZ/EL motors   │ │  CC1200 UHF + VHF     │       │
                  └─────────────────┘ └───────────────────────┘       │
```

## Current Pi State

| Item | Value |
|---|---|
| Model | Pi 3 Model A+ (512 MB RAM) |
| OS | Raspberry Pi OS Bookworm arm64 |
| IP | 10.72.3.105 |
| User | pi / satnogs123 |
| WiFi | "maakleerplek - cowork" (NetworkManager/nmcli) |
| USB | Rotator Pico → /dev/ttyACM0 |
| UART | RF HAT Pico → /dev/serial0 (GPIO14 TXD, GPIO15 RXD) |

## What's Already Installed

- `libhamlib-utils` (provides `rotctld`, `rotctl`)
- `rotctld.service` — systemd service, model 204, listening on 0.0.0.0:4533
- SatNOGS client framework (Docker + Ansible) — needs station registration to go live
- Python 3 with `pip`

## RF Data Flow — UHF Receive + VHF Transmit

The ground station uses **Mode V/U**, the standard amateur satellite convention:
- **UHF (432 MHz) = downlink / receive** — AetherSpace CubeSat transmits at 433 MHz
- **VHF (145 MHz) = uplink / transmit** — commands sent to CubeSat at 145.9 MHz

SatNOGS itself is **receive-only** (no uplink). The VHF TX path is custom, outside SatNOGS.

### Data flow during a satellite pass

```
    CelesTrak TLE ──→ PyEphem orbit prediction
                            │
                            ├──→ AZ/EL ──→ rotctld ──→ Rotator Pico ──→ motors
                            │
                            └──→ range rate ──→ Doppler shift
                                                  │
                         ┌────────────────────────┤
                         │                        │
                  UHF RX freq adjust       VHF TX freq adjust
                  (433 MHz ± Δf)           (145 MHz ± Δf)
                         │                        │
                         └────── RF HAT Pico ─────┘
                                    │
                              /dev/serial0
                                    │
                         ┌──────────┴──────────┐
                         │  Packet log file    │
                         │  Console output     │
                         │  SiDS submission    │
                         └─────────────────────┘
```

### Pi-side Python scripts

| Script | Purpose | Radio | Interface |
|---|---|---|---|
| `rf_hat.py` | Core protocol library (import, don't run) | Both | UART |
| `capture.py` | Standalone UHF packet capture | UHF (433 MHz) | UART |
| `transmit.py` | Standalone VHF packet transmitter | VHF (145 MHz) | UART |
| `station.py` | Full pass controller (rotator + RX + TX + Doppler) | Both | UART + TCP |
| `dashboard.py` | Web dashboard — live station status page | — | TCP (rotctld) + JSON file |
| `buzzer.py` | Buzzer driver (AOS/LOS/packet beeps via RF HAT Pico) | — | UART (via rf_hat.py) |

### `rf_hat.py` — Protocol library

Shared library imported by all other scripts. Handles:
- **COBS framing** + CRC-16/CCITT-FALSE (matches firmware protocol)
- **CC1200Link** class with threaded RX loop and event queue
- All protocol commands: PING, GET_INFO, SELECT_RADIO, SET_STATE, SET_STREAMING, GET_METRICS
- Register access: read/write normal and extended CC1200 registers
- TX: write to FIFO, transmit, flush
- **Frequency helpers**: `freq_to_regs()`, `regs_to_freq()`, `doppler_shift()`
- **SmartRF profile loading**: parse TI SmartRF Studio exports, apply via register writes

### `capture.py` — UHF Packet Capture

Standalone receiver. Opens UART, selects UHF radio, loads SmartRF profile, enables
RX streaming, and logs all received packets.

```bash
python3 capture.py                                  # defaults (433 MHz)
python3 capture.py --freq 435.0                     # specific frequency
python3 capture.py --log packets.log                # log to file
python3 capture.py --port /dev/ttyUSB0              # alternate serial port
python3 capture.py --duration 300                   # capture for 5 minutes
```

### `transmit.py` — VHF Packet Transmitter

Sends packets on the VHF CC1200 (145 MHz uplink).

```bash
python3 transmit.py "48 65 6C 6C 6F"               # hex payload
python3 transmit.py --ascii "Hello CubeSat"         # ASCII string
python3 transmit.py --file cmd.bin                  # binary file
python3 transmit.py --freq 145.9 "DE ON4SAT"        # custom freq (MHz)
python3 transmit.py --repeat 5 --interval 2 "AA BB" # repeat 5x, 2s apart
python3 transmit.py --power 0x3F "test"             # set PA power level
```

### `dashboard.py` — Web Dashboard & Field Control Center

Self-contained HTTPS dashboard using only the Python standard library (no Flask).
Opens `https://<pi-ip>:5000` in any browser — designed for phone-first field use.

```bash
python3 dashboard.py                    # default: HTTPS on port 5000
python3 dashboard.py --port 8080        # custom port
python3 dashboard.py --no-ssl           # HTTP only (GPS won't work from phone)
```

**Features:**
- **Phone GPS**: tap "Set Location" → browser Geolocation API sends lat/lon/elev to Pi
- **Park Antenna**: sends park command to rotctld
- **Shutdown Pi**: parks antenna, then safely shuts down
- **Live status**: rotator AZ/EL, RF RSSI/packets, pass progress, system health

**HTTPS:** The dashboard auto-generates a self-signed certificate (stored in
`~/.station_ssl/`). This is required because the browser Geolocation API only
works over HTTPS. First visit: tap "Advanced → Proceed" in the browser warning.

**Endpoints:**
| Method | Path | Description |
|---|---|---|
| GET | `/` | HTML dashboard page |
| GET | `/api/status` | JSON status blob (polled every 1s by JS) |
| POST | `/api/location` | Save `{lat, lon, elev}` to `~/station.conf` |
| POST | `/api/park` | Send park command to rotctld |
| POST | `/api/shutdown` | Park + `sudo shutdown -h now` |

**How it works:** Polls rotctld (TCP 4533) for AZ/EL and reads
`~/.station_status.json` (written by `station.py` during a pass) for RF metrics.

### `buzzer.py` — Audio Feedback

Sends beep commands to the RF HAT Pico over UART. The passive buzzer is on **Pico GP2**
(driven via switching transistor + hardware PWM). The Pico plays tones locally —
the Pi just sends a pattern ID.

| Event | Sound | Frequency |
|---|---|---|
| Station ready | Triple beep | 1000 Hz |
| AOS (satellite rise) | Rising two-tone | 800 → 1200 Hz |
| LOS (satellite set) | Falling two-tone | 1200 → 800 Hz |
| Packet received | Short high beep | 1500 Hz |
| Error | Low tone 0.5s | 400 Hz |

Hardware: passive piezo buzzer on Pico GP4 with NPN/MOSFET switching transistor.
Requires an open CC1200Link (passed to constructor). Falls back gracefully when
no link is available (beeps are silently skipped, e.g., `--no-rf` mode).

### `station.py` — Full Station Controller

The main script for a real satellite pass. Orchestrates all three subsystems:

1. **Rotator tracking** — sends AZ/EL to rotctld at 10 Hz
2. **UHF packet capture** — CC1200 RX streaming at 433 MHz
3. **Doppler correction** — updates CC1200 FREQ registers in real-time (2 Hz)
4. **VHF TX** (optional) — transmit a command packet after the pass

```bash
# Manual operation:
python3 station.py                                  # auto-pick next pass
python3 station.py --sat "ISS"                      # track specific satellite
python3 station.py --list                           # list upcoming passes
python3 station.py --sat "ISS" --no-rf              # rotator only
python3 station.py --sat "ISS" --doppler            # enable Doppler correction
python3 station.py --sat "ISS" --tx cmd.bin         # TX on VHF after pass
python3 station.py --log pass.log                   # log everything to file

# Daemon mode (auto-start, no SSH needed):
python3 station.py --daemon --no-rf --doppler       # wait for GPS, loop passes
```

**Daemon mode** (`--daemon`): designed for systemd auto-start. Waits for
`~/station.conf` (set from phone GPS via dashboard), then continuously:
fetches TLEs → finds passes → tracks them → sleeps → repeats. No SSH needed.

**Station location** is resolved in priority order:
1. `--lat`/`--lon`/`--elev` CLI flags
2. `~/station.conf` (JSON file, set via dashboard GPS or manually)
3. Hardcoded defaults (KU Leuven Campus Geel)

### SmartRF register profiles

| File | Band | Frequency | Status |
|---|---|---|---|
| `configs/smartrf_uhf_435.txt` | UHF (410-480 MHz) | 435 MHz | Verified from SmartRF Studio |
| `configs/smartrf_vhf_145.txt` | VHF (136-160 MHz) | 145.9 MHz | Adapted from UHF — needs VNA tuning |
| `configs/cc1200_regmap_profile.json` | — | — | Register name → address mapping |

The VHF config has only the frequency registers changed (FS_CFG, FREQ2/1/0). The FS synthesizer
registers may need re-tuning via SmartRF Studio for optimal VHF performance.

### Frequency register math

The CC1200 frequency is set by four registers:

```
FS_CFG[3:0]  = FSD_BANDSELECT  →  selects LO divider
FREQ[23:0]   = frequency word   →  sets actual frequency

f_RF = FREQ × f_XOSC / (LO_div × 2^16)
FREQ = round(f_RF × LO_div × 2^16 / f_XOSC)
```

| Band | FSD_BANDSELECT | LO divider | FS_CFG | Frequency range |
|---|---|---|---|---|
| 820-960 MHz | 0x02 | 4 | 0x12 | — |
| 410-480 MHz | 0x04 | 8 | 0x14 | UHF (433 MHz) |
| 273-320 MHz | 0x06 | 12 | 0x16 | — |
| 164-192 MHz | 0x0A | 20 | 0x1A | — |
| 136-160 MHz | 0x0B | 24 | 0x1B | VHF (145 MHz) |

Crystal frequency: 40 MHz (RF HAT hardware).

**UHF 433 MHz**: FS_CFG=0x14, FREQ=0x560000 → f = 5,636,096 × 40M / (8 × 65536) = 430.0 MHz
(profile default; `set_frequency()` overrides to exact target)

**VHF 145.9 MHz**: FS_CFG=0x1B, FREQ=0x578A3D → f = 5,737,021 × 40M / (24 × 65536) = 145.9 MHz

### Doppler correction

At 433 MHz, a LEO satellite at ~7.5 km/s causes up to ±10 kHz Doppler shift.
At 145 MHz, the shift is about ±3.5 kHz. The CC1200's channel filter is typically
25-100 kHz wide, so Doppler correction is optional for wide filters but important
for narrow filters or coherent demodulation.

`station.py --doppler` computes the shift from PyEphem's `range_velocity` and updates
the CC1200 FREQ registers at 2 Hz during the pass.

## Step-by-Step Setup

### 1. Fresh OS Install (if starting from scratch)

Flash **Raspberry Pi OS Bookworm arm64 Lite** (no desktop needed) using Raspberry Pi Imager.
In the imager settings, set hostname, enable SSH, and configure WiFi.

```bash
# After first boot, SSH in:
ssh pi@10.72.3.105

# Update
sudo apt update && sudo apt upgrade -y
```

### 2. Enable UART for RF HAT

The Pi's hardware UART (GPIO14/15) is used by the RF HAT Pico. On Bookworm, it needs to be
enabled and the serial console disabled (so it doesn't interfere):

```bash
# Add to /boot/firmware/config.txt:
sudo tee -a /boot/firmware/config.txt > /dev/null << 'EOF'

# Enable UART for RF HAT Pico communication
enable_uart=1
dtoverlay=disable-bt
EOF

# Disable serial console (frees /dev/serial0 for our use)
sudo systemctl disable serial-getty@ttyAMA0.service
sudo systemctl stop serial-getty@ttyAMA0.service

# Remove console=serial0 from cmdline.txt if present
sudo sed -i 's/console=serial0,[0-9]* //g' /boot/firmware/cmdline.txt

sudo reboot
```

After reboot, `/dev/serial0` should exist and point to `/dev/ttyAMA0` (the PL011 UART).

**Verify:**
```bash
ls -la /dev/serial0
# Should show: /dev/serial0 -> ttyAMA0

# Quick test (if RF HAT Pico is connected):
pip install pyserial
python3 -c "
import serial
s = serial.Serial('/dev/serial0', 115200, timeout=1)
print('UART open:', s.name)
s.close()
"
```

### 3. Install Rotator Control (hamlib)

```bash
sudo apt install -y libhamlib-utils

# Create systemd service
sudo tee /etc/systemd/system/rotctld.service > /dev/null << 'EOF'
[Unit]
Description=Hamlib rotctld for SatNOGS rotator
After=network.target
StartLimitIntervalSec=60
StartLimitBurst=5

[Service]
Type=simple
ExecStart=/usr/bin/rotctld -m 204 -r /dev/ttyACM0 -s 115200 -T 0.0.0.0
Restart=always
RestartSec=5
User=pi

[Install]
WantedBy=multi-user.target
EOF

sudo systemctl daemon-reload
sudo systemctl enable --now rotctld

# Verify
rotctl -m 2 -r localhost:4533 p    # should return AZ/EL position
```

**Note:** `-m 204` = SatNOGS rotator (EasyComm3). `-T 0.0.0.0` makes it accessible from
any machine on the network (useful for testing from your laptop).

### 4. Install Pi-side Python Tools

```bash
# Install dependencies
pip install pyserial ephem

# Clone the repo on the Pi (or copy just the Pi/ directory):
git clone <repo-url> ~/SatNOGS-Basestation
cd ~/SatNOGS-Basestation/Pi

# Test RF HAT connection
python3 -c "
from rf_hat import CC1200Link
link = CC1200Link()
link.open('/dev/serial0')
import time; time.sleep(0.1)
print('PING:', link.ping())
link.close()
"

# Test UHF capture (Ctrl+C to stop)
python3 capture.py --duration 10

# Test VHF transmit
python3 transmit.py --ascii "test"

# Full station pass
python3 station.py --list              # see upcoming passes
python3 station.py --sat "ISS"         # track ISS with RX
python3 station.py --sat "ISS" --doppler --log iss_pass.log
```

### 5. Install SatNOGS Client (Optional)

The SatNOGS client handles observation scheduling, rotator control, and data submission.
It's Docker-based and needs ~1 GB RAM — tight on the 512 MB Pi 3 A+.

```bash
# Official Ansible installer
curl -sfL https://satno.gs/install | sh -s --

# Run setup wizard
sudo satnogs-setup
```

Configuration values:
```
SATNOGS_API_TOKEN=<from network.satnogs.org after station registration>
SATNOGS_STATION_ID=<your station ID>
SATNOGS_STATION_LAT=51.1
SATNOGS_STATION_LON=4.97
SATNOGS_STATION_ELEV=25
SATNOGS_ROT_MODEL=ROT_MODEL_NETROTCTL
SATNOGS_ROT_PORT=localhost:4533
```

**If RAM is too tight:** Run satnogs-client on a Pi 3B+/4, or skip Docker and run
`rotctld` + `station.py` manually.

## How Everything Runs Together

### Scenario A: Field Deployment (recommended — no SSH needed)

Install services once, then everything auto-starts on boot:

```bash
# One-time setup (via SSH):
bash ~/SatNOGS-Basestation/Pi/services/install.sh
```

After reboot, the field workflow is:
1. Place station, point north, power on
2. Open `https://<pi-ip>:5000` on your phone
3. Tap "Set Location from GPS"
4. Station auto-tracks passes, dashboard shows live status
5. Tap "Park" or "Shutdown" when done

Services: `rotctld` + `dashboard` + `station` (daemon mode) all start on boot.

### Scenario A2: Manual Pass (specific satellite, SSH)

```bash
# rotctld + dashboard are already running as services

# Track a specific satellite:
python3 station.py --sat "ISS" --doppler --log passes/iss.log
```

**What happens:**
1. `station.py` fetches TLEs from CelesTrak
2. Finds the next pass for the requested satellite
3. Connects to `rotctld` (TCP 4533) for rotator control
4. Opens RF HAT via UART, loads UHF SmartRF profile, tunes to 433 MHz
5. Pre-positions rotator to AOS azimuth
6. At AOS: starts RX streaming + begins tracking at 10 Hz
7. During pass: updates AZ/EL, polls for RX packets, optionally corrects Doppler at 2 Hz
8. At LOS: stops RX, parks rotator, logs summary
9. Optionally transmits a VHF command packet after the pass

### Scenario B: Separate Tracking + Capture

Run station controller and RF capture in separate terminals:

```bash
# Terminal 1: rotctld is already running as a service
sudo systemctl status rotctld

# Terminal 2: satellite tracking + RF (all-in-one)
python3 ~/SatNOGS-Basestation/Pi/station.py --sat "ISS" --doppler

# Terminal 3: (optional) standalone UHF packet capture
python3 ~/SatNOGS-Basestation/Pi/capture.py --log packets.log
```

### Scenario C: SatNOGS Automated + station.py RF

Run SatNOGS for scheduling and rotator control. Run RF capture as a systemd service:

```bash
sudo tee /etc/systemd/system/rf-capture.service > /dev/null << 'EOF'
[Unit]
Description=RF HAT CC1200 UHF packet capture
After=network.target

[Service]
Type=simple
WorkingDirectory=/home/pi/SatNOGS-Basestation/Pi
ExecStart=/usr/bin/python3 /home/pi/SatNOGS-Basestation/Pi/capture.py --log /home/pi/packets.log
Restart=always
RestartSec=5
User=pi

[Install]
WantedBy=multi-user.target
EOF

sudo systemctl daemon-reload
sudo systemctl enable --now rf-capture
```

## Connection Details

### UART — RF HAT Pico

| Pi Side | RF HAT Pico Side | Wire |
|---|---|---|
| GPIO14 (TXD) | GP1 (UART0 RX) | Pi TX → Pico RX |
| GPIO15 (RXD) | GP0 (UART0 TX) | Pico TX → Pi RX |
| GND | GND | Common ground |

Settings: 115200 baud, 8N1, no flow control.

On Bookworm with `enable_uart=1` and `dtoverlay=disable-bt`, the UART appears as:
- `/dev/serial0` → symlink to `/dev/ttyAMA0` (PL011 hardware UART)

The protocol is **binary** (not text like the rotator). See
[RF HAT Protocol](../Firmware/rp2040-rf-hat/README.md#binary-protocol-cobs-over-uart) for details.

### USB Serial — Rotator Pico

| Interface | Device | Protocol |
|---|---|---|
| USB serial | /dev/ttyACM0 | Text-based EasyComm (115200 baud) |

If the Pico disconnects/reconnects, the device name might change (`ttyACM1`, etc.).
To make it persistent, create a udev rule:

```bash
# Find the Pico's serial number
udevadm info /dev/ttyACM0 | grep SERIAL

# Create udev rule for a fixed symlink
sudo tee /etc/udev/rules.d/99-satnogs-rotator.rules > /dev/null << 'EOF'
SUBSYSTEM=="tty", ATTRS{idVendor}=="2e8a", ATTRS{idProduct}=="000a", SYMLINK+="satnogs-rotator"
EOF

sudo udevadm control --reload-rules
sudo udevadm trigger
# Now /dev/satnogs-rotator always points to the Rotator Pico
```

Then update the rotctld service to use `/dev/satnogs-rotator` instead of `/dev/ttyACM0`.

## Quick Test Commands

### Test rotator (from any machine on the network)

```bash
# Query position
echo "p" | nc 10.72.3.105 4533

# Move to AZ 180, EL 45
echo "P 180.0 45.0" | nc 10.72.3.105 4533

# Park (return to 0, 0)
echo "P 0.0 0.0" | nc 10.72.3.105 4533

# Using rotctl directly on the Pi
rotctl -m 2 -r localhost:4533 p           # query
rotctl -m 2 -r localhost:4533 P 90.0 30.0 # move
```

### Test RF HAT (on the Pi)

```bash
cd ~/SatNOGS-Basestation/Pi

# Ping test — verifies UART + COBS + CRC are working
python3 -c "
from rf_hat import CC1200Link
link = CC1200Link()
link.open('/dev/serial0')
import time; time.sleep(0.1)
print('PING:', link.ping())
info = link.get_info()
if info: print(f'Part: 0x{info.part:02X}, Ver: 0x{info.ver:02X}')
link.close()
"

# Quick UHF capture (10 seconds)
python3 capture.py --duration 10

# Quick VHF TX test
python3 transmit.py --ascii "test"

# Full pass with ISS
python3 station.py --sat "ISS" --doppler
```

## Pi Directory Structure

```
Pi/
├── README.md               ← this file (setup + technical reference)
├── requirements.txt        ← pip dependencies (pyserial, ephem)
├── rf_hat.py               ← CC1200 protocol library (shared)
├── rf_backend.py           ← RF backend abstract base class
├── capture.py              ← UHF packet capture script
├── transmit.py             ← VHF packet transmit script
├── station.py              ← full station pass controller (+ daemon + scan mode)
├── dashboard.py            ← HTTPS web dashboard + field control center
├── buzzer.py               ← buzzer driver (sends patterns to RF HAT Pico GP4)
├── sat_library.py          ← satellite profile database + SatNOGS DB API
├── satnogs.py              ← SiDS telemetry submission client
├── wifi_provision.py       ← WiFi captive portal for field setup
├── (offline decoders live in ../tools/: ax100_decoder.py, decode_ax100.py,
│    decode_serial.py, usp_decoder.py — run on captured .raw files)
├── services/
│   ├── install.sh              ← one-command service installer
│   ├── setup-pi.sh             ← fresh Pi setup script
│   ├── dashboard.service       ← systemd: dashboard on boot
│   └── station.service         ← systemd: auto-tracker on boot (daemon mode)
├── configs/
│   ├── cc1200_regmap_profile.json  ← register name → address map
│   ├── smartrf_uhf_435.txt         ← UHF SmartRF profile (verified)
│   └── smartrf_vhf_145.txt         ← VHF SmartRF profile (adapted, needs tuning)
└── docs/
    ├── quickstart.md               ← 5-minute field quick start guide
    ├── satnogs_integration.md      ← SatNOGS ecosystem documentation
    └── satellite_pipeline.md       ← satellite data pipeline overview
```

## Known Issues / TODO

- [ ] **VHF matching network** needs VNA tuning (SmartRF profile adapted from UHF, not optimized)
- [ ] **udev rules** — persistent device names for both Picos (currently `/dev/ttyACM0` can shift)

## Troubleshooting

### Rotator Pico not appearing as /dev/ttyACM0
- Check USB cable (data cable, not charge-only)
- Try `ls /dev/ttyACM*` — might be ttyACM1 if something else claimed ACM0
- Pi micro-USB undervoltage can brownout USB — use a quality cable and power supply

### UART not working (/dev/serial0 missing)
- Verify `enable_uart=1` is in `/boot/firmware/config.txt`
- Verify `dtoverlay=disable-bt` is in `/boot/firmware/config.txt`
- Verify serial console is disabled: `sudo systemctl status serial-getty@ttyAMA0.service`
- Check `dmesg | grep -i uart` for kernel messages
- On Bookworm, the config file is at `/boot/firmware/config.txt` (not `/boot/config.txt`)

### RF HAT PING fails
- Check UART wiring: Pi GPIO14 (TX) → Pico GP1 (RX), Pi GPIO15 (RX) → Pico GP0 (TX)
- Ensure common GND between Pi and RF HAT
- Verify RF HAT Pico is powered and running (LED should blink)
- Try `python3 -c "import serial; s=serial.Serial('/dev/serial0', 115200); print(s.name)"` to verify port opens

### WiFi drops on Pi 3 A+
- Bookworm uses NetworkManager (not wpa_supplicant)
- Reconfigure: `sudo nmcli dev wifi connect "SSID" password "PASS"`
- Headless WiFi config at first boot is unreliable on Bookworm — configure via ethernet first

### SatNOGS Docker out of memory
- Pi 3 A+ has only 512 MB RAM — Docker + SatNOGS is tight
- Add swap: `sudo dphys-swapfile swapoff && sudo sed -i 's/CONF_SWAPSIZE=.*/CONF_SWAPSIZE=1024/' /etc/dphys-swapfile && sudo dphys-swapfile setup && sudo dphys-swapfile swapon`
- Or use a Pi 3B+ / Pi 4 with more RAM
- Or skip SatNOGS Docker entirely and run rotctld + station.py manually

### rotctld fails to start
- Check if Pico is connected: `ls /dev/ttyACM0`
- Check service status: `sudo systemctl status rotctld`
- Test manually: `rotctld -m 204 -r /dev/ttyACM0 -s 115200 -vvv` (verbose mode)

### No packets received during a pass
- Check RSSI in metrics output — if below -120 dBm, antenna/matching may be wrong
- Verify frequency: `station.py` logs the actual CC1200 frequency readback
- Check MARCSTATE: should be 0x0D (RX) during capture, not 0x01 (IDLE)
- Ensure CC1200 part number reads 0x20 (not 0x00 which means SPI failure)
- Try without Doppler first (`--no-doppler`) to rule out frequency update issues

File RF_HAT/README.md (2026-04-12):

# RF_HAT — Dual CC1200 Transceiver HAT for Raspberry Pi

KiCad 9.0 project for a Raspberry Pi 3A+ HAT with two TI CC1200 transceivers (UHF 432 MHz + VHF 144 MHz), controlled by a Raspberry Pi Pico over SPI. Part of the [SatNOGS Basestation](../README.md) project.

A rough estimate for 1 board, assembled by JLCPCB, for 10 units, is 20USD per board. This converges to 10USD in larger quantities.

## Architecture

```
Pi 3A+ (40-pin header)
  └─ UART ─── Raspberry Pi Pico (SPI host + 3.3V supply)
                 ├─ SPI0 ─── CC1200 #2 (VHF 144 MHz) ─── SMA
                 └─ SPI1 ─── CC1200 #1 (UHF 432 MHz) ─── SMA
```

**Power**: External buck converter provides 5V through a Schottky diode to the Pico's VSYS pin (USB can power simultaneously via internal Schottky OR-ing). Pico's onboard RT6150 regulator provides 3.3V for both CC1200s.

## File Structure

| Path | Description |
|---|---|
| `RF_HAT_out/` | KiCad project (open `RF_HAT.kicad_pro` in KiCad 9) |
| `rf_hat_circuit.py` | Original circuit-synth source (reference only — board is now edited directly in KiCad) |
| `datasheets/` | CC1200 datasheet, CC120x user guide, TI reference designs |

## RF Matching Network — 3-Path Topology

Each CC1200 shares a single SMA antenna through three RF paths: TX matching, RX differential balun, and TRX coupling switch. The CC1200's internal TRX_SW pin handles TX/RX switching.

```
PA BIAS PATH (DC feed to PA pin):
    AVDD_FILT ─── R_PA(18Ω) ──┬── L4(56nH) ─── PA pin 17
                     C5(56pF)──┘
                     across R_PA

TX MATCHING (PA → SMA):
    PA pin 17 ─── C2(39pF) ─┬─ L1(15nH) ─┬─ L2(43nH) ─┬─ L3(22nH) ─┬─ C10(1nF) ── SMA
                             |              |             |             |   DC block
                       C1(2.2pF)──┘    C3(5.1pF)    C4(6.2pF)
                       feedback         to TRX_SW    to GND

TRX COUPLING (TX/RX switch):
    TRX_SW pin 18 ──┬── C3(5.1pF) ── mn2 (L1/L2 junction)
                    └── L5(15nH)  ── balun center

LNA DIFFERENTIAL BALUN (RX input):
    LNA_P pin 19 ──┬── L7(56nH) ── LNA_N pin 20    (bridge inductor)
                   ├── L6(27nH) ── GND               (bias path)
                   └── C8(5.1pF) ── balun center      (coupling)

    LNA_N pin 20 ──┬── L7(56nH) ── LNA_P             (bridge)
                   ├── L8(27nH) ── balun center       (from TRX)
                   └── C9(5.1pF) ── GND               (shunt)
```

## Component Values

### Inductors (per CC1200)

| Ref | Function | UHF 432 MHz | VHF 144 MHz |
|-----|---|---|---|
| L1 | TX match #1 | 15nH | 22nH |
| L2 | TX match #2 | 43nH | 120nH |
| L3 | TX match #3 | 22nH | 82nH |
| L4 | PA RF choke | 56nH | 270nH |
| L5 | TRX coupling | 15nH | 47nH |
| L6 | LNA_P bias to GND | 27nH | 100nH |
| L7 | LNA bridge (P-N) | 56nH | 180nH |
| L8 | LNA_N to balun | 27nH | 100nH |

### Capacitors (per CC1200)

| Ref | Function | UHF 432 MHz | VHF 144 MHz |
|-----|---|---|---|
| C1 | TX feedback | 2.2pF | 1.5pF |
| C2 | TX series (PA-mn1) | 39pF | 100pF |
| C3 | TRX coupling | 5.1pF | 15pF |
| C4 | TX shunt | 6.2pF | 15pF |
| C5 | PA bias bypass | 56pF | 100pF |
| C6 | PA AVDD decoupling | 10nF | 10nF |
| C7 | PA AVDD decoupling | 100pF | 100pF |
| C8 | LNA_P balun coupling | 5.1pF | 15pF |
| C9 | LNA_N shunt | 5.1pF | 15pF |
| C10 | DC block before SMA | 1nF | 100pF |

### Common elements (both bands)

| Component | Value | Source |
|---|---|---|
| Crystal | 40 MHz, NDK NX3225SA | SWRS123D Section 4.14 |
| Crystal load caps | 15 pF | SWRS123D |
| RBIAS | 56k | CC120X standard |
| DCPL caps | 100 nF x4 | SWRS123D Figure 6-1 |
| Ferrite bead | 1k@100MHz | BLM15HG102SN1D |
| SPI series resistors | 100R x3 | EMI reduction |
| CS/RESET pull-ups | 10k x2 | Float prevention |

## Value Sources

**UHF 432 MHz**: M17 CC1200_HAT Rev B (SP5WWP/DB9MAT, verified +14dBm at 433.475 MHz). Cross-referenced with TI SWRR122 (CC1200EM 420-470 MHz reference design).

**VHF 144 MHz**: Adapted from TI CC1120EM 169 MHz design (TIDR220/TIDR222). No official TI reference exists for 136-160 MHz. Inductors scaled ~17% for 144 MHz. **VNA tuning required during board bring-up.**

## GPIO Assignments (Pico)

| Function | GPIO | Function | GPIO |
|---|---|---|---|
| UART TX | GP0 | VHF MISO | GP16 |
| UART RX | GP1 | VHF CSN | GP17 |
| UHF GPIO3 | GP6 | VHF SCLK | GP18 |
| UHF GPIO0 | GP7 | VHF MOSI | GP19 |
| UHF RESET | GP8 | VHF RESET | GP20 |
| UHF GPIO2 | GP9 | VHF GPIO2 | GP21 |
| UHF SCLK | GP10 | VHF GPIO0 | GP22 |
| UHF MOSI | GP11 | VHF GPIO3 | GP26 |
| UHF MISO | GP12 | | |
| UHF CSN | GP13 | | |

## PCB Fabrication (JLCPCB 6-Layer)

The board is configured for JLCPCB's **JLC06121H-3313** 6-layer stackup (1.2mm nominal):

| Layer | Type | Thickness | Material | Er |
|---|---|---|---|-----|
| F.Cu | Copper | 0.035mm (1oz) | — | — |
| Dielectric 1 | Prepreg 3313 | 0.0994mm | NP-155F | 4.1 |
| In1.Cu | Copper | 0.0152mm (0.5oz) | — | — |
| Dielectric 2 | Core | 0.35mm | NP-155F | 4.36 |
| In2.Cu | Copper | 0.0152mm (0.5oz) | — | — |
| Dielectric 3 | Prepreg 2116 | 0.1164mm | NP-155F | 4.16 |
| In3.Cu | Copper | 0.0152mm (0.5oz) | — | — |
| Dielectric 4 | Core | 0.35mm | NP-155F | 4.36 |
| In4.Cu | Copper | 0.0152mm (0.5oz) | — | — |
| Dielectric 5 | Prepreg 3313 | 0.0994mm | NP-155F | 4.1 |
| B.Cu | Copper | 0.035mm (1oz) | — | — |

### Impedance Control

RF traces to the SMA connectors use a `50Ohm` net class (0.15mm / 6 mil width), calculated for F.Cu microstrip over In1.Cu ground plane (h=0.0994mm, Er=4.1, 1oz copper). Verify with [JLCPCB's impedance calculator](https://jlcpcb.com/pcb-impedance-calculator) before ordering.

### Ordering Notes

- Select **6-layer**, **1.2mm** thickness, **ENIG** surface finish (free for 6-layer)
- Enable **impedance control** and specify stackup **JLC06121H-3313**
- Dielectric constraints are enabled in the KiCad project (`dielectric_constraints yes`)

## Reference Documents

| Document | Title | Used For |
|---|---|---|
| M17 CC1200_HAT | M17-Project/CC1200_HAT-hw (GitHub) | Primary UHF topology + values |
| SWRS123D | CC1200 Datasheet | Pin functions, crystal, DCPL caps |
| SWRR122 | CC1200EM 420-470 MHz Reference Design | UHF matching cross-check |
| SWRU346 | CC120X User Guide (114 pages) | Register config, RF design |
| TIDR220 | CC1120EM 169 MHz Schematic | VHF matching topology |
| TIDR222 | CC1120EM 169 MHz BOM | VHF component part numbers |
| TIDU921 | Multiband wM-Bus RF Subsystem | Bypass cap values |
| TIDU512 | CC1120 169 MHz wM-Bus Design | Additional VHF reference |

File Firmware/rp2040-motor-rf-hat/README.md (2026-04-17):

# rp2040-motor-rf-hat — v2 scaffold

**Status:** scaffold only. Target board (`MOTOR_RF_HAT/`) is design-complete and routed but **not yet fabricated**. This firmware is **not compiled, not flashed, and not currently under active development.**

## Purpose

When the v2 MOTOR_RF_HAT PCB is built, this tree locks in:

- The v2 pin plan (`src/config.h`) — AZ/EL motor drivers on GP2/3 (A4950, 2-pin PWM), AZ/EL encoders on GP14/15 and GP21/... , SPI0 shared between VHF CC1200 and ADXL345 IMU.
- The combined protocol surface — EasyComm rotator commands + COBS RF HAT protocol on a single UART to the Pi.
- The combined-board main loop scaffolding.

## What's missing (do on v2 board arrival)

1. Merge the current `../rp2040-rf-hat/src/` into this tree:
   - `ax25_decode.c/h` (AX.25 G3RUH software decoder)
   - `serial_rx.pio.h` (PIO synchronous bitstream capture)
   - Any post-April-12 changes to `proto.c`, `main.cpp`, `config.h`.
2. Merge the current `../rp2040-satnogs-rotator/src/` rotator code:
   - `rotator.cpp/h`, `motor_pwm.cpp/h`, `quadrature.cpp/h`, `adxl345.cpp/h`, `satnogs_protocol.cpp/h`, `status_led.cpp/h`, `pins.h`.
3. Resolve any pin conflicts against this tree's v2 `config.h`.
4. Build with `pio run`, flash via BOOTSEL, verify on the v2 board.

## Why not keep in sync continuously?

Keeping a half-merged fork in lockstep with two evolving firmwares (rotator + RF HAT) before the target hardware exists is more technical debt than leverage — v1 firmware improvements were adopted on v1 boards in the field, and re-merging once at v2 board arrival is less error-prone than continuously triple-maintaining. This directory therefore represents the **most recent frozen pin plan** for v2, not a buildable image.

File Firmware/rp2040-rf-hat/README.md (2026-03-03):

# RF HAT Firmware — Dual CC1200 Controller

PlatformIO firmware for the RF HAT Pico, controlling two TI CC1200 sub-GHz transceivers
(UHF 432 MHz + VHF 144 MHz) and communicating with the Raspberry Pi 3A+ over UART.

Based on [CC1200RXFrontend](https://github.com/RobbeLehaen/CC1200RXFrontend) by Robbe Lehaen,
adapted for the RF HAT dual-radio hardware.

See the [Firmware README](../README.md) for how this fits into the full ground station system.

## Architecture

```
Pi 3A+ (satnogs-client + packet capture)
  │
  ├── USB serial (/dev/ttyACM0) ──→ Motor Pico   (rotator, hamlib/rotctld)
  │
  └── UART (GPIO14/15, 115200)  ──→ RF HAT Pico  (this firmware)
                                      ├── SPI1 → CC1200 UHF (432 MHz)
                                      └── SPI0 → CC1200 VHF (144 MHz)
```

## Quick Start

```bash
cd Firmware/rp2040-rf-hat
pio run                    # build → rf_hat_firmware.uf2 (copied to repo root)
pio run -t upload          # flash via BOOTSEL
pio device monitor         # USB debug serial (115200)
```

## Hardware Pin Map (from `rf_hat_circuit.py`)

| Function | GPIO | Pico Pin | Notes |
|---|---|---|---|
| **UART TX** | GP0  | 1 | → Pi GPIO15 (RXD)  |
| **UART RX** | GP1  | 2 | ← Pi GPIO14 (TXD)  |
| **UHF SCLK** | GP10 | 14 | SPI1 |
| **UHF MOSI** | GP11 | 15 | SPI1 |
| **UHF MISO** | GP12 | 16 | SPI1 |
| **UHF CSN** | GP13 | 17 | SPI1 |
| **UHF RESET** | GP8  | 11 | |
| **UHF GPIO0** | GP7  | 10 | |
| **UHF GPIO2** | GP9  | 12 | |
| **UHF GPIO3** | GP6  | 9 | |
| **VHF SCLK** | GP18 | 24 | SPI0 |
| **VHF MOSI** | GP19 | 25 | SPI0 |
| **VHF MISO** | GP16 | 21 | SPI0 |
| **VHF CSN** | GP17 | 22 | SPI0 |
| **VHF RESET** | GP20 | 26 | |
| **VHF GPIO0** | GP22 | 29 | |
| **VHF GPIO2** | GP21 | 27 | |
| **VHF GPIO3** | GP26 | 31 | |
| **Buzzer** | GP4  | 6 | Passive piezo via NPN/MOSFET |
| **NeoPixel** | GP5  | 7 | 4x WS2812B status LEDs |
| **LED** | GP25 | — | Pico onboard |

## How the Codebase Works

### CC1200 Driver (`lib/cc1200_driver/`)

Hardware-agnostic CC1200 SPI driver, originally from Robbe's CC1200RXFrontend.
Bug-fixed in this version (see [Code Review Notes](#code-review-notes--bug-fixes)).

| File | Lines | Purpose |
|---|---|---|
| `cc1200_hal.h` | ~60 | HAL struct definition + inline helpers |
| `cc1200_hal.c` | 106 | RP2040 SPI + GPIO initialization, chip-select with SO-ready wait, reset pulse, raw SPI transfer |
| `cc1200.h` | ~100 | CC1200 API: register/FIFO/strobe/extended access, command enums |
| `cc1200.c` | 239 | All CC1200 SPI transactions: single reg, burst, extended, FIFO, strobes |

**Key types:**

- **`cc1200_hal_t`** — HAL configuration struct:
  - `spi_inst_t* spi` — Pico SDK SPI instance (spi0 or spi1)
  - `pin_sck/mosi/miso/csn/reset` — GPIO assignments
  - `baud_hz` — SPI clock rate (5 MHz)
  - `so_ready_timeout_us` — max wait time for MISO low after CSN assert (5 ms)
  - `cfg_burst_interbyte_delay_cycles` — computed at init for >=100 ns delay between burst writes

- **`cc1200_t`** — Device handle. Contains a `cc1200_hal_t` member. One per physical CC1200.

- **`cc1200_status_t`** — Decoded chip status byte:
  - `chip_ready` — bit 7 inverted (0 = ready)
  - `state` — bits 6:4 (IDLE, RX, TX, FSTXON, CALIBRATE, SETTLING, RXFIFO_ERROR, TXFIFO_ERROR)
  - `fifo_bytes` — bits 3:0 (number of bytes available in FIFO)

- **`cc1200_cmd_t`** — Strobe commands: `SRES` (0x30), `SRX` (0x34), `STX` (0x35), `SIDLE` (0x36), `SFRX` (0x3A), `SFTX` (0x3B), etc.

**CC1200 SPI protocol (from SWRS123D datasheet):**

The CC1200 uses a byte-oriented SPI interface. Every transaction starts by pulling CSN low
and waiting for SO (MISO) to go low — this is the "SO-ready" handshake indicating the CC1200's
internal state machine is ready. The first byte sent is a header that encodes the operation:

```
Header byte: [R/W(1)] [BURST(1)] [ADDR(6)]

Bit 7: 1 = read, 0 = write
Bit 6: 1 = burst (auto-increment address), 0 = single
Bits 5:0: register address
```

Register spaces:
- **Standard registers** (0x00-0x2E): 2-byte transfer (header + data)
- **Extended registers** (via address 0x2F): 3-byte transfer (0x2F header + ext_addr + data)
- **Strobes** (0x30-0x3D): 1-byte command, returns status byte
- **FIFO** (0x3F): burst read/write for packet data

For burst writes to the config register space (0x00-0x2E), the CC1200 requires a minimum
100 ns inter-byte delay. The HAL computes the required NOP count at init time based on the
system clock frequency.

**`cc1200_hal_init()`** — Initializes the SPI peripheral, configures GPIO functions, sets up CSN
as a GPIO output (initially high), configures the reset pin, and computes the burst delay.

**`cc1200_hal_select()`** — Pulls CSN low, then polls MISO until it reads 0 (or timeout).
This is critical — the CC1200 holds MISO high while its crystal is starting or while it's
processing the previous command.

**`cc1200_begin()`** — Full reset sequence: hardware reset pulse (1ms low, 1ms post), then
send SRES strobe, then wait for SO-ready again. After this, the CC1200 is in IDLE state with
default register values.

### Firmware (`src/`)

| File | Lines | Purpose |
|---|---|---|
| `main.cpp` | ~230 | Arduino entry point: init UART + both CC1200s + NeoPixel + buzzer + protocol handler, main loop |
| `config.h` | ~60 | Pin definitions, SPI baud rates, radio constants |
| `proto.c` | 542 | Full binary protocol handler: COBS frame parsing, command dispatch, profile staging, RX streaming, TX helpers |
| `proto.h` | 63 | Message type enums and API |
| `cobs.c` | ~80 | COBS encoder/decoder |
| `cobs.h` | ~20 | COBS API |
| `crc16.c` | ~30 | CRC-16/CCITT-FALSE implementation |
| `crc16.h` | ~15 | CRC API |

#### Entry Point (`main.cpp`)

`setup()` runs:

1. **USB serial** (115200 baud) — debug output only, not used for protocol
2. **Onboard LED** configured for heartbeat
3. **NeoPixel** (4x WS2812B on GP3) — all white during init
4. **Buzzer** (GP2 PWM) — hardware PWM initialized
5. **UART0** initialized at 115200 baud, GP0 TX, GP1 RX, 8N1, FIFO enabled
6. **UHF CC1200** initialized on SPI1 — `init_radio()` configures the HAL, calls `cc1200_begin()` (hardware reset + SRES strobe), then reads part number register (ext addr 0x8F) to verify CC1200 responds (expected: 0x20)
7. **VHF CC1200** initialized on SPI0 — same sequence
8. **Protocol handler** initialized with both radio instances + buzzer callback
9. **NeoPixel** → green + triple beep if both radios OK; red + error beep if either failed

`loop()` runs:
- **500ms heartbeat**: toggle LED + update NeoPixel color (green=idle, blue=RX streaming, red=fault)
- **`buzzer_tick()`**: advance non-blocking buzzer tone sequencer
- **`proto_poll()`**: read UART bytes, decode COBS frames, dispatch commands, stream RX data
- **1ms yield**: `delay(1)` for USB serial processing

#### Protocol Handler (`proto.c`)

This is the heart of the firmware. It implements a binary request/response protocol over UART
using COBS framing.

**Frame structure on the wire:**
```
┌──────────────────────────────┐
│ COBS_ENCODE(payload) │ 0x00  │   ← wire bytes
└──────────────────────────────┘
         │
         ▼ (after COBS decode)
┌──────┬─────┬──────┬──────────┬───────┐
│ type │ seq │ len  │   body   │ crc16 │   ← payload
│  1B  │ 1B  │ 2B   │  len B   │  2B   │
│      │     │  LE  │          │  LE   │
└──────┴─────┴──────┴──────────┴───────┘
```

**COBS (Consistent Overhead Byte Stuffing):** Replaces all 0x00 bytes in the payload with
distance-to-next-zero markers, then uses a 0x00 byte as the frame delimiter. This guarantees
the delimiter never appears inside the frame — no escaping ambiguity, low overhead (~0.4%).

**`proto_poll()`** — Called from the main loop. Reads bytes from UART0:
- Non-zero bytes are accumulated in `g_rx_enc[]` (max 512 bytes)
- A 0x00 byte triggers end-of-frame processing:
  1. COBS-decode the accumulated bytes into `g_rx_dec[]`
  2. Validate minimum frame size (6 bytes: type + seq + len + crc)
  3. Verify payload length matches encoded length field
  4. Compute CRC-16 over the header+body and compare with the received CRC
  5. If valid, call `handle_cmd()` with the message type, sequence, and body
- After processing commands, calls `maybe_stream_rx()` to push any pending RX FIFO data

**`handle_cmd()`** — Giant switch statement dispatching on message type:

- **`MSG_PING` (0x01)**: Returns "PONG" — basic connectivity test
- **`MSG_GET_INFO` (0x02)**: Returns active radio index, radio count, CC1200 part number and version
- **`MSG_SELECT_RADIO` (0x40)**: Switches active radio (0=UHF, 1=VHF). Resets streaming and clears any staged profile.
- **`MSG_SET_STATE` (0x03)**: Sends SIDLE, SRX, or STX strobe to the active CC1200
- **`MSG_SET_STREAMING` (0x04)**: Enables/disables automatic RX FIFO push (via `maybe_stream_rx()`)
- **`MSG_GET_METRICS` (0x05)**: Reads MARCSTATE, RX FIFO count, and RSSI (12-bit, converted to dBm x10)
- **`MSG_READ_REG`/`MSG_WRITE_REG` (0x10/0x11)**: Standard register access (0x00-0x2E)
- **`MSG_READ_EXT`/`MSG_WRITE_EXT` (0x12/0x13)**: Extended register access
- **`MSG_RX_READ` (0x20)**: Read up to N bytes from RX FIFO
- **`MSG_STROBE` (0x21)**: Send a strobe command (validated to 0x30-0x3D range)
- **`MSG_TX_WRITE` (0x22)**: Write data to TX FIFO with optional IDLE/flush before write
- **`MSG_TX_SEND` (0x23)**: Send STX strobe with optional post-TX state (IDLE or RX)
- **`MSG_TX_FLUSH` (0x24)**: Flush TX FIFO
- **`MSG_PROFILE_*` (0x30-0x33)**: Bulk register configuration (see below)

**Profile system:**
The profile system allows loading a complete SmartRF Studio register configuration in chunks,
then applying it atomically:

1. `PROFILE_CLEAR` — reset staging buffer
2. `PROFILE_BEGIN` — start a new profile load (up to 768 entries)
3. `PROFILE_CHUNK` — append register entries: each is `[type(1) addr(1) val(1)]` where type bit 0 selects extended (1) vs standard (0) register space
4. `PROFILE_APPLY` — force IDLE, poll MARCSTATE to confirm, write all staged registers, then optionally flush FIFOs and/or enter RX

**RX streaming (`maybe_stream_rx()`):**
When streaming is enabled, this function polls `NUM_RXBYTES` and reads the RX FIFO in 64-byte
chunks, sending each as an `EVT_RX_DATA` event frame. This allows the Pi to receive packets
without polling — the Pico pushes data as it arrives.

**RSSI calculation (`read_metrics()`):**
The CC1200 provides a 12-bit signed RSSI value across two registers (RSSI1 and RSSI0[7:4]).
The firmware sign-extends this, scales it to dBm x10 (divide by 16, multiply by 10), and also
provides a 1-byte integer dBm approximation. An RSSI of -2048 means "not valid" (not yet measured).

**`send_frame()`** — Builds a response/event frame:
1. Assemble payload: type + seq + len(LE) + body + CRC-16(LE)
2. COBS-encode into `g_tx_enc[]`
3. Write encoded bytes + 0x00 delimiter to UART0

### PC/Pi Test Tools (`tools/`)

| File | Purpose |
|---|---|
| `cc1200_gui.py` | Python GUI (CustomTkinter) for interactive CC1200 control: register read/write, profile load, RX streaming, RSSI display |
| `cc1200_diag.py` | CLI diagnostic tool: ping, info, register dump, profile load, RX test |
| `generate_regmap.py` | Generates `cc1200_regmap_all.json` from TI's `cc120x_spi.h` header file |
| `cc120x_spi.h` | TI CC120X register definitions (source for generate_regmap.py) |
| `cc1200_regmap_all.json` | Complete register name→address map (generated) |
| `cc1200_regmap_profile.json` | Profile-applicable registers only (subset) |
| `smartrf_config.txt` | SmartRF Studio register export (435 MHz, 2.4 kbps, 2-GFSK) |

The Python tools implement the same COBS protocol and can talk to the Pico over either
USB serial (original Robbe setup) or UART serial (via a USB-UART adapter or directly from the Pi).

## Binary Protocol (COBS over UART)

### Frame Format

```
Wire: COBS_ENCODE(payload) + 0x00 delimiter

Payload: type(1) + seq(1) + len(2 LE) + body(len) + crc16(2 LE)
```

CRC-16/CCITT-FALSE: poly=0x1021, init=0xFFFF, no refin/refout, xorout=0.

### Message Types

**Control:**
| Code | Name | Body (request) | Body (response) |
|---|---|---|---|
| 0x01 | PING | — | "PONG" |
| 0x02 | GET_INFO | — | active(1) count(1) part(1) ver(1) |
| 0x03 | SET_STATE | state(1): 0=IDLE 1=RX 2=TX | ok(1) |
| 0x04 | SET_STREAMING | enable(1) | enabled(1) |
| 0x05 | GET_METRICS | — | marc(1) rxbytes(1) rssi_1db(i8) rssi_dbm_x10(i16 LE) |
| 0x40 | SELECT_RADIO | index(1): 0=UHF 1=VHF | active(1) |
| 0x50 | BUZZER | pattern(1) | ok(1) |

BUZZER pattern IDs: 0x01=ready (triple beep), 0x02=AOS (rising), 0x03=LOS (falling), 0x04=packet (short), 0x05=error (low).

**Register I/O:**
| Code | Name | Body (request) | Body (response) |
|---|---|---|---|
| 0x10 | READ_REG | addr(1) | ok(1) value(1) |
| 0x11 | WRITE_REG | addr(1) value(1) | ok(1) |
| 0x12 | READ_EXT | ext_addr(1) | ok(1) value(1) |
| 0x13 | WRITE_EXT | ext_addr(1) value(1) | ok(1) |

**FIFO / Strobes:**
| Code | Name | Body | Response |
|---|---|---|---|
| 0x20 | RX_READ | max_bytes(1) | count(1) data(count)  |
| 0x21 | STROBE | cmd(1) [0x30-0x3D]  | status_raw(1) |

**TX:**
| Code | Name | Body | Response |
|---|---|---|---|
| 0x22 | TX_WRITE  | flags(1) count(1) data(count)  | ok(1) written(1) |
| 0x23 | TX_SEND | flags(1) | ok(1) |
| 0x24 | TX_FLUSH  | — | ok(1) |

TX_WRITE flags: bit 0 = flush TX FIFO before write, bit 1 = IDLE before write.
TX_SEND flags: bit 0 = IDLE after TX, bit 1 = RX after TX, bit 2 = flush TX FIFO first.

**Profile (bulk register config from SmartRF Studio):**
| Code | Name | Body | Response |
|---|---|---|---|
| 0x30 | PROFILE_CLEAR  | — | ok(1) |
| 0x31 | PROFILE_BEGIN  | expected_count(2 LE) | ok(1) |
| 0x32 | PROFILE_CHUNK  | count(1) [type(1) addr(1) val(1)] x count | ok(1) total(2 LE)  |
| 0x33 | PROFILE_APPLY  | flags(1) | ok(1) |

PROFILE_CHUNK type field: bit 0 = 1 for extended register, 0 for standard register.
PROFILE_APPLY flags: bit 0 = enter RX, bit 1 = IDLE, bit 2 = flush RX FIFO, bit 3 = flush TX FIFO.

**Responses** have `type | 0x80` and mirror the request `seq`.
**Async events** use `seq=0`: `0xE0` EVT_RX_DATA, `0xE1` EVT_ERROR.

### Typical Usage Sequence

```
1. PING                        → verify connectivity
2. GET_INFO                    → check CC1200 part number
3. SELECT_RADIO(0)             → select UHF
4. PROFILE_CLEAR               → reset profile buffer
5. PROFILE_BEGIN(count)         → start profile load
6. PROFILE_CHUNK(entries...)    → send register values (multiple chunks)
7. PROFILE_APPLY(0x05)         → apply profile, flush RX, enter RX
8. SET_STREAMING(1)            → enable RX data push
9. ... receive EVT_RX_DATA ... → packets arrive asynchronously
10. GET_METRICS                → check RSSI, MARCSTATE
```

## SmartRF Register Config (435 MHz)

The included `smartrf_config.txt` configures:

| Parameter | Value |
|---|---|
| Frequency | 435.000 MHz |
| Modulation | 2-GFSK |
| Symbol rate | ~2.4 ksps |
| Deviation | ~5.0 kHz |
| RX bandwidth | ~29.8 kHz |
| TX power | +14 dBm (max) |
| Packet format | Variable-length, CRC-16 |
| Sync word | 16-bit: 0x7A0E  |
| Preamble | 3 bytes of 0xAA |

The modulation index (~4.17) is higher than typical for 2-GFSK at this data rate. This is
intentional for the AetherSpace CubeSat link budget — wider deviation improves sensitivity
at the cost of occupied bandwidth.

## Code Review Notes / Bug Fixes

Issues found in the original CC1200RXFrontend code. All except #2 have been **fixed** in this version:

1. **`send_frame()` buffer overflow** (FIXED) — COBS output could exceed `TX_ENC_MAX` (was 512)
   for payloads near max size. Fixed: increased to 520 and capped body_len at `sizeof(g_tx_payload) - 8`.

2. **`cc1200_read_status()` broken** (NOT FIXED — function unused) — Uses standard-space header
   for status registers that live in extended space. The function exists in the driver but is never
   called. Use `cc1200_read_ext()` instead for reading status registers.

3. **`profile_apply()` didn't confirm IDLE** (FIXED) — After SIDLE strobe, registers were written
   immediately without confirming the CC1200 had actually entered IDLE state. Fixed: now polls
   MARCSTATE for up to 5ms after SIDLE strobe.

4. **Burst inter-byte delay borderline** (FIXED) — The 100 ns inter-byte delay for config register
   burst writes was exactly at the CC1200 minimum (12 NOPs at 125 MHz = 96 ns). Fixed: added
   +2 cycle margin to guarantee >=100 ns.

5. **No strobe range validation** (FIXED) — `MSG_STROBE` accepted any byte value. Sending a
   value outside 0x30-0x3D would trigger an unintended register read/write instead of a command
   strobe. Fixed: range check added, returns error for invalid values.

6. **Register address check too loose** (FIXED) — `cc1200_read_reg()`/`cc1200_write_reg()` used
   `(addr & 0xC0u) != 0` which allowed addresses 0x2F-0x3F through (including the extended access
   prefix and strobes). Fixed: changed to `addr > 0x2Eu`.

## SatNOGS Integration

SatNOGS is SDR-centric (GNU Radio + SoapySDR). The CC1200 is a **hardware packet modem**, not an SDR —
it does not produce IQ samples. Integration options:

1. **Recommended**: Run `satnogs-client` for rotator scheduling + pointing. Capture CC1200 packets
   independently via a Python script on the Pi (reading UART). Submit decoded frames to
   [SatNOGS DB](https://db.satnogs.org/) via the SiDS API.

2. **Tighter**: Use satnogs-client pre/post observation scripts to automate CC1200 tuning and
   packet capture around scheduled passes.

3. **Doppler**: Write a minimal `rigctld` shim that translates `set_freq` hamlib commands to
   CC1200 frequency register writes via the UART protocol.

4. **Hybrid**: Add an RTL-SDR (~8 EUR) for standard SatNOGS waterfall/audio/IQ artifacts.
   Use CC1200 as the primary packet decoder (hardware demod = more reliable for narrow-band FSK).

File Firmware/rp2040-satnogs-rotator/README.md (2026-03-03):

# rp2040-satnogs-rotator

RP2040 Pico firmware for the SatNOGS rotator controller. Part of the [SatNOGS Basestation](../../README.md) project — see also [`MotorPCB/`](../../MotorPCB/) for the KiCad PCB this firmware runs on.

See the [Firmware README](../README.md) for how this fits into the full ground station system.

## Quick Start

```bash
pio run              # build → firmware.uf2 (copied to repo root)
pio run -t upload    # flash (Pico must be in BOOTSEL mode)
pio device monitor   # USB serial console (115200 baud)
```

## Source Files

| File | Lines | Purpose |
|---|---|---|
| `main.cpp` | ~195 | Arduino entry point, IMU-based EL homing, encoder IRQ setup, main loop (100 Hz tick + serial parser + heartbeat + NeoPixel) |
| `pins.h` | 42 | GPIO pin map — extracted from `MotorPCB/motorPCB.net` KiCad netlist |
| `config.h` | 62 | All calibration constants: encoder ticks/deg, PID gains, duty limits, soft limits, homing params |
| `motor_pwm.cpp/h` | 81/30 | TB6642FG H-bridge driver: direction via IN1/IN2 GPIOs, speed via hardware PWM (20 kHz) |
| `quadrature.cpp/h` | 55/24 | Quadrature encoder decoder: ISR-driven, 4x decoding via Gray-code state transition table |
| `rotator.cpp/h` | ~430/122 | Closed-loop PID controller, homing state machine, AZ shortest-path wrapping, cable-wrap recentering, runaway detection, endstop + fault safety gates |
| `satnogs_protocol.cpp/h` | 250/~30 | EasyComm command parser + bench test commands (DUTY, TICKS, MONITOR, GAINS, IMU, etc.) |
| `adxl345.cpp/h` | ~120/~40 | ADXL345 accelerometer driver (SPI0): reads gravity vector, computes elevation angle |
| `status_led.cpp/h` | ~80/~20 | NeoPixel RGB status LED on GP16: idle (green), tracking (blue), on-target (cyan), fault (red) |

## How the Codebase Works

### Entry Point (`main.cpp`)

`setup()` runs once at boot:

1. **USB CDC serial** initialized (115200 baud) — this is the command interface to the Pi
2. **NeoPixel status LED** initialized on GP16
3. **Motor PWM** — two `MotorPwm` instances created for AZ and EL, configured at 20 kHz
4. **Quadrature encoders** — two `Quadrature` instances, with GPIO edge interrupts enabled on all 4 encoder pins via a shared ISR callback
5. **Rotator** — the `Rotator` object takes ownership of motors and encoders
6. **ADXL345 IMU** — probed on SPI0
7. **AZ calibration** — encoder zeroed (assumes antenna points north at power-on)
8. **EL homing** — if IMU found, the motor physically drives EL to horizontal (0°) using IMU feedback, then zeros the encoder. Timeout after 15s falls back to IMU-based static calibration. If no IMU, EL assumed 0° (antenna must be placed horizontal before power-on).
9. **Protocol handler** — `SatnogsProtocol` wraps the Rotator and optional IMU

The main loop runs inside `setup()` (not in Arduino's `loop()`), timed by `get_absolute_time()`:

- **100 Hz**: `rotator.tick()` — reads encoders, runs PID, drives motors
- **1 Hz**: LED heartbeat toggle + NeoPixel state update (idle/tracking/on-target/fault)
- **20+ Hz**: NeoPixel animation update (blink patterns)
- **10 Hz**: optional monitor stream (if `MONITOR` command is active)
- **Always**: serial character accumulation → line-based command dispatch

### Motor Driver (`motor_pwm.cpp`)

Drives the TB6642FG in IN1/IN2 direction mode:

- **Forward**: IN1=HIGH, IN2=LOW, PWM sets speed
- **Reverse**: IN1=LOW, IN2=HIGH, PWM sets speed
- **Stop**: IN1=LOW, IN2=LOW, PWM=0

The PWM frequency is computed from the system clock (125 MHz default):
```
f_pwm = f_sys / (clkdiv × (wrap + 1))
```
At 20 kHz with 125 MHz system clock: wrap = 6249, giving 16-bit duty resolution.

The `set(float duty)` method takes a signed value (-1.0 to +1.0) — sign controls direction,
magnitude controls duty cycle.

### Quadrature Decoder (`quadrature.cpp`)

Uses 4x decoding: both rising and falling edges on both A and B channels trigger the ISR.
The ISR reads the current AB state, combines it with the previous state to form a 4-bit index
into a lookup table that returns -1, 0, or +1:

```
State transition table (last_state << 2 | new_state):
AB: 00→01 = -1,  00→10 = +1
    01→00 = +1,  01→11 = -1
    10→00 = -1,  10→11 = +1
    11→01 = +1,  11→10 = -1
```

The `volatile int32_t ticks_` counter is updated atomically in the ISR. `set_ticks()` allows
calibration routines to preset the counter (e.g., from IMU elevation reading).

A shared GPIO IRQ callback (`gpio_irq_callback` in main.cpp) dispatches to the correct
`Quadrature` instance by checking which GPIO triggered the interrupt.

### PID Controller (`rotator.cpp`)

The `Rotator::tick()` method runs the control loop at 100 Hz:

1. **Measure**: read encoder ticks, convert to degrees via `ticks_per_deg` and invert flag
2. **Fault check**: read TB6642FG ALERT pins (active-high = fault)
3. **Runaway detection**: if actual position exceeds soft limits by more than 50°, emergency stop all motors (safety gate against positive-feedback failures)
4. **Mode dispatch**: manual mode skips PID; homing mode runs the homing state machine
5. **PID compute** (per axis):
   - Compute error = target - measured
   - If |error| < deadband (0.05 deg): output zero, clear PID state
   - Otherwise: compute P + I + D terms
   - D-term uses exponential low-pass filter (alpha=0.15) to suppress encoder noise spikes
   - I-term has anti-windup clamp (max 5 deg-seconds)
   - Output clamped to [-kMaxDuty, +kMaxDuty] (95%)
   - No minimum duty floor — the I-term naturally overcomes stiction
6. **Motor inversion**: the `kAzInvert`/`kElInvert` flags flip both the position reading (in `ticks_to_deg()`) and the motor output (in `update_control()`). Both must be inverted together — inverting only the position creates positive feedback (runaway)
7. **Duty smoothing**: exponential filter (alpha=0.05) on the PID output prevents start/stop twitching during continuous satellite tracking
8. **Endstop safety**: if an endstop is pressed and the error points into it, stop that motor
9. **AZ recentering**: after the rotator settles near ±360°, the encoder is shifted by one full turn to bring AZ back near 0°. This prevents cable-wrap accumulation across multiple passes

### AZ Shortest-Path Wrapping

When a new AZ target is set, `choose_wrapped_target()` picks the equivalent angle (target, target+360, or target-360) that is closest to the current position while staying within the soft limits (±360°). This means:

- Tracking north-crossing passes (e.g. AZ 350° → AZ 10°) takes the short 20° path, not the long 340° path
- PARK from AZ -310° goes to -360° (equivalent to 0°, 50° away) instead of the long way to 0° (310°)
- The logic is in the firmware, so it works identically whether commands come from the Python tracker, rotctld on the Pi, or any other hamlib client

### Homing (`rotator.cpp`)

When `kUseEndstopHoming = true`, the `RESET` command triggers homing:

1. Both axes run simultaneously, each with their own state machine
2. **Phase 0**: drive in `kHomeFirstDir` direction at `kHomeDuty` (25%) for up to `kHomePhaseTimeoutMs` (10s)
3. **Phase 1**: if endstop not found, reverse direction for another 10s
4. When endstop triggers (GPIO reads active): stop motor, zero encoder, mark axis homed
5. Global timeout of 20s aborts homing if both axes aren't found

Currently disabled (`kUseEndstopHoming = false`) — the IMU provides absolute EL reference and
AZ is assumed north at power-on.

### EasyComm Protocol (`satnogs_protocol.cpp`)

Compatible with hamlib model 204 (`ROT_MODEL_EASYCOMM3`). Response format echoes the command
prefix because hamlib strips the first 2 characters.

**SatNOGS commands (hamlib-compatible):**

| Command | Response | Action |
|---|---|---|
| `AZ` or `EL` | `AZ<f> EL<f>\n` | Query current position |
| `AZ<f>` | (none) | Set AZ target, enter PID mode |
| `EL<f>` | (none) | Set EL target, enter PID mode |
| `AZ<f> EL<f>` | (none) | Set both targets atomically |
| `VE` | `VESatNOGS-RP2040-v0.2\n` | Version query |
| `GS` | `GS<n>\n` | Status: 1=idle, 2=moving |
| `GE` | `GE<n>\n` | Error: 1=OK, 4=not homed, 8=driver fault |
| `SA` | `AZ<f> EL<f>\n` | Stop azimuth |
| `SE` | `AZ<f> EL<f>\n` | Stop elevation |
| `STOP` or `S` | `AZ<f> EL<f>\n` | Stop all motors |
| `RESET` or `R` | `AZ<f> EL<f>\n` | Start homing sequence |
| `PARK` | `AZ<f> EL<f>\n` | Go to park position (AZ 0, EL 0) |

**Bench test commands (bypass PID):**

| Command | Response | Action |
|---|---|---|
| `DUTY_AZ<f>` | `AZ duty=<f>\n` | Set raw AZ motor duty (-1..1) |
| `DUTY_EL<f>` | `EL duty=<f>\n` | Set raw EL motor duty (-1..1) |
| `TICKS` | `AZ_TICKS=<n> EL_TICKS=<n>\n` | Print encoder tick counts |
| `ZERO` or `Z` | `Encoders zeroed\n` | Reset encoder counters |
| `MONITOR` or `MON` | `MONITOR ON/OFF\n` | Toggle 10 Hz status stream |
| `INFO` | Multi-line dump | Full status (position, ticks, endstops, alerts, mode) |
| `GAINS` | `KP=<f> KI=<f> KD=<f>\n` | Show current PID gains |
| `KP<f>` / `KI<f>` / `KD<f>` | `KP=<f> KI=<f> KD=<f>\n` | Set PID gain at runtime |
| `IMU` | `X=<f> Y=<f> Z=<f> g EL=<f> deg\n` | Read accelerometer |
| `RECAL` | `EL recalibrated from IMU: <f> deg\n` | Reset EL reference from IMU |
| `HELP` or `?` | Command list | Print help |

### IMU-Based EL Homing (`main.cpp` + `adxl345.cpp`)

At boot, the ADXL345 accelerometer on SPI0 provides an absolute elevation reference from the gravity vector. The firmware uses this to physically home the EL axis:

1. Read IMU to get current elevation angle (averaged over 10 samples)
2. Drive EL motor toward 0° (horizontal) at 25% duty
3. Continuously read IMU (averaged over 3 samples) to check progress
4. When IMU reads within ±1.5° of horizontal: stop motor, zero encoder
5. Timeout after 15 seconds — if homing fails, calibrate encoder from IMU's last reading as fallback
6. If IMU not detected: EL assumed 0° (antenna must be placed horizontal before power-on)

The `RECAL` command re-reads the IMU and recalibrates EL at any time during operation.

**IMU mounting**: the ADXL345 is mounted on the Motor PCB with X-axis pointing up at EL=0° (horizontal). Elevation is computed as `atan2(z, x)` from the gravity vector.

## GPIO Pin Map

Extracted from `MotorPCB/motorPCB.net` (KiCad netlist, U5 = Pico module):

| Function | GPIO | Pico Pin | Notes |
|---|---|---|---|
| AZ IN1 | GP15 | 20 | TB6642FG direction |
| AZ IN2 | GP14 | 19 | TB6642FG direction |
| AZ PWM | GP22 | 29 | Hardware PWM (20 kHz) |
| AZ ALERT | GP19 | 25 | Fault detect (active-high) |
| AZ Encoder A | GP11 | 15 | Swapped A↔B for correct direction |
| AZ Encoder B | GP10 | 14 | Swapped A↔B for correct direction |
| AZ Endstop | GP8 | 11 | Active-low with pull-up |
| EL IN1 | GP28 | 34 | Swapped IN1↔IN2 for correct direction |
| EL IN2 | GP27 | 32 | Swapped IN1↔IN2 for correct direction |
| EL PWM | GP21 | 27 | Hardware PWM (20 kHz) |
| EL ALERT | GP20 | 26 | Fault detect (active-high) |
| EL Encoder A | GP12 | 16 | |
| EL Encoder B | GP13 | 17 | |
| EL Endstop | GP9 | 12 | Active-low with pull-up |
| IMU MISO | GP4 | 6 | SPI0 (ADXL345) |
| IMU CS | GP5 | 7 | SPI0 |
| IMU SCK | GP6 | 9 | SPI0 |
| IMU MOSI | GP7 | 10 | SPI0 |
| LED | GP25 | — | Pico onboard |

## Configuration (`config.h`)

| Parameter | Default | Description |
|---|---|---|
| `kUseEndstopHoming` | `false` | Enable endstop homing on RESET |
| `kIgnoreDriverFaults` | `true` | Ignore TB6642FG ALERT (set false with 24V supply) |
| `kAzTicksPerDegree` | 244.6 | Encoder ticks per degree of AZ output rotation |
| `kElTicksPerDegree` | 126.1 | Encoder ticks per degree of EL output rotation |
| `kAzInvert` | `false` | Invert AZ encoder direction |
| `kElInvert` | `true` | Invert EL encoder direction |
| `kKp` / `kKi` / `kKd` | 0.15 / 0.03 / 0.02 | PID gains (tunable at runtime) |
| `kDeadbandDeg` | 0.05 | Position deadband in degrees |
| `kMaxDuty` | 0.95 | Max PWM duty (95% = ~35 deg/s) |
| `kPwmHz` | 20000 | PWM frequency |
| `kDtSeconds` | 0.01 | Control loop period (100 Hz) |
| `kDFilterAlpha` | 0.15 | D-term low-pass filter coefficient |
| `kDutyFilterAlpha` | 0.05 | Duty output smoothing coefficient |
| `kAzMinDeg` / `kAzMaxDeg` | -360 / +360 | AZ soft limits |
| `kElMinDeg` / `kElMaxDeg` | 0 / 180 | EL soft limits |
| `kParkAzDeg` / `kParkElDeg` | 0 / 0 | Park position |

## Speed Test Results (24V)

| Duty | Speed (deg/s) | 360 deg time |
|---|---|---|
| 35% | 11.2 | 32s |
| 55% | 18.9 | 19s |
| 75% | 26.9 | 13s |
| 95% | 35.0 | 10s |

Speed scales linearly with duty up to 95%. At 100%, TB6642FG overcurrent protection can trigger on motor stall.

## Integration with Pi

On the Pi, the rotator appears as `/dev/ttyACM0`. Run:

```bash
# Start rotator daemon
rotctld -m 204 -r /dev/ttyACM0 -s 115200 -T 0.0.0.0 &

# Test from command line
rotctl -m 2 -r localhost:4533 P 180.0 45.0   # point to AZ 180, EL 45
rotctl -m 2 -r localhost:4533 p               # query position
```

SatNOGS client connects to `rotctld` via netrotctl — no custom software needed.

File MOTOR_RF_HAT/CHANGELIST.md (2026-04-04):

# MOTOR_RF_HAT Changelist

Combined Motor Control + RF HAT board. Merges MotorPCB functionality onto
the RF HAT Pi HAT, single RP2040 Pico, single UART to Pi.

## GPIO Pin Map (new combined board)

| GPIO | Function | Peripheral | Notes |
|---|---|---|---|
| GP0 | UART TX | UART0 | → Pi GPIO15 (RXD) |
| GP1 | UART RX | UART0 | ← Pi GPIO14 (TXD) |
| GP2 | AZ Motor IN1 | PWM1A | A4950 — PWM this pin for forward |
| GP3 | AZ Motor IN2 | PWM1B | A4950 — PWM this pin for reverse |
| GP4 | NeoPixel data | PIO | WS2812B chain (4x or 2x) |
| GP5 | Buzzer | PWM2B | Passive buzzer via MOSFET |
| GP6 | UHF GPIO3 | GPIO | CC1200 CCA (optional, can cut) |
| GP7 | UHF GPIO0 | GPIO | CC1200 PKT_SYNC_RXTX |
| GP8 | UHF RESET | GPIO out | CC1200 active-low reset |
| GP9 | UHF GPIO2 | GPIO | CC1200 MARC status (optional, can cut) |
| GP10 | UHF SPI SCK | SPI1 | CC1200 UHF 5 MHz |
| GP11 | UHF SPI MOSI | SPI1 | |
| GP12 | UHF SPI MISO | SPI1 | |
| GP13 | UHF SPI CSN | SPI1 | |
| GP14 | AZ Encoder A | GPIO IRQ | Quadrature, ISR on rise/fall |
| GP15 | AZ Encoder B | GPIO IRQ | |
| GP16 | VHF SPI MISO | SPI0 | Shared bus with IMU (mode switch) |
| GP17 | VHF SPI CSN | SPI0 CS | |
| GP18 | VHF SPI SCK | SPI0 | Shared bus with IMU |
| GP19 | VHF SPI MOSI | SPI0 | Shared bus with IMU |
| GP20 | VHF RESET | GPIO out | |
| GP21 | EL Encoder A | GPIO IRQ | Quadrature, ISR on rise/fall |
| GP22 | EL Encoder B | GPIO IRQ | |
| GP23 | EL Motor IN1 | PWM3B | A4950 — PWM this pin for forward |
| GP24 | EL Motor IN2 | PWM4A | A4950 — PWM this pin for reverse |
| GP25 | Onboard LED | GPIO out | Pico module LED (heartbeat) |
| GP26 | IMU SPI CS | GPIO out | ADXL345, manual CS, shared SPI0 bus |
| GP27 | VHF GPIO0 | GPIO | (optional, can cut) |
| GP28 | VHF GPIO2 | GPIO | (optional, can cut) |
| GP29 | SPARE | — | Available for debug/future |

**Total: 29 used + 1 spare (GP29)**

### SPI0 bus sharing (GP16/18/19)

SPI0 is shared between the ADXL345 IMU and VHF CC1200. They use different
SPI modes (IMU=mode 3, CC1200=mode 0) but never operate simultaneously:

1. Boot: SPI0 configured mode 3 @ 1 MHz → ADXL345 homing
2. After homing: reconfigure SPI0 to mode 0 @ 5 MHz → VHF CC1200 active
3. RECAL command: temporarily switch to mode 3, read IMU, switch back

Both devices have separate CS pins (GP26 for IMU, GP17 for VHF).

### Optional GPIO cuts (if more pins needed)

These CC1200 GPIOx pins are NOT used in current firmware (polling-based):
- GP6 (UHF GPIO3): save 1 pin
- GP9 (UHF GPIO2): save 1 pin
- GP27 (VHF GPIO0): save 1 pin
- GP28 (VHF GPIO2): save 1 pin

Cutting all 4 frees GP6, GP9, GP27, GP28, GP29 = **5 spare**.

---

## Schematic Changes (rf_hat_circuit.py)

### ADD: Motor driver section (2x A4950ELJTR-T)

Each A4950 needs:
- VBB (pin 5): 24V motor supply, 100nF + 10µF bypass
- GND (pin 1): ground
- IN1 (pin 3): RP2040 GPIO (PWM-capable)
- IN2 (pin 2): RP2040 GPIO (PWM-capable)
- OUT1 (pin 6): motor terminal A
- OUT2 (pin 8): motor terminal B
- VREF (pin 4): tie to VBB via 10k divider for ~3A limit, or tie to VBB to disable current limiting
- LSS (pin 7): tie to GND (no sense resistor)
- PAD: solder to ground pour (thermal)

Bypass caps per driver: 100nF ceramic + 10µF electrolytic on VBB pin.

### ADD: Motor/encoder connectors

- J_AZ_MOTOR: 2-pin JST-XH (motor A+/A-)
- J_EL_MOTOR: 2-pin JST-XH (motor B+/B-)
- J_AZ_ENC: 4-pin JST-XH (VCC, GND, A, B)
- J_EL_ENC: 4-pin JST-XH (VCC, GND, A, B)

Encoder power: 3.3V from Pico (encoders are 3.3V compatible on FAPG36-555-EN).

### ADD: ADXL345 IMU (SPI, SOIC-14 or LGA-14)

- SPI0 shared bus: SCK=GP18, MOSI=GP19, MISO=GP16
- CS: GP26 (manual, active-low, 10k pull-up)
- VCC: 3.3V, bypass 100nF + 10µF
- INT1/INT2: not connected (polling only)
- SDO/ALT ADDRESS: tie to VCC for SPI mode (vs I2C)

### MODIFY: Power architecture

**Remove**: Second LMR51420 buck (only need one)

**Keep**: One LMR51420 (24V→5V, 2A) for Pico + CC1200s + NeoPixels + buzzer

**Add**: 24V direct rail to A4950 VBB pins with:
- LC filter between 24V input and CC1200 AVDD domain
- 100µF bulk electrolytic on 24V motor rail
- Ferrite bead (600Ω @ 100MHz) isolating motor 24V from buck 24V input
- 2x 100nF + 10µF per A4950 VBB

**Keep**: XT30PW-M 24V input connector (single, shared)

### MODIFY: NeoPixel

Change from WS2812B-2020 to **WS2812B-5050** (larger, easier to solder).
Reduce to 2 LEDs (motor status + RF status) or keep 4 with distinct roles:
- LED1: Motor/tracking status (green=idle, blue=tracking, cyan=on-target)
- LED2: RF status (green=UHF OK, red=fault)
- LED3: Pass indicator (off=no pass, blue=tracking, yellow=AOS imminent)
- LED4: System (white blink = heartbeat)

Move data pin from GP5 to **GP4**.

### MODIFY: Buzzer

Move from GP5 to **GP5** (unchanged). Keep BSS138 MOSFET driver circuit.

### REMOVE (optional)

Nothing mandatory to remove. VHF CC1200 stays. Second LMR51420 removed.

---

## Firmware Changes

### New unified firmware: `Firmware/rp2040-motor-rf-hat/`

Fork from `Firmware/rp2040-rf-hat/`, add motor control modules from
`Firmware/rp2040-satnogs-rotator/`.

### Files to copy from rp2040-satnogs-rotator → rp2040-motor-rf-hat

| File | Changes needed |
|---|---|
| `motor_pwm.h/cpp` | Refactor from 3-pin (IN1,IN2,PWM) to 2-pin (IN1,IN2). PWM whichever IN pin is active. Remove dedicated PWM GPIO. |
| `quadrature.h/cpp` | Pin numbers change only (GP14/15 for AZ, GP21/22 for EL) |
| `rotator.h/cpp` | No changes — uses MotorPwm and Quadrature interfaces |
| `adxl345.h/cpp` | Add SPI mode switching before/after access |
| `satnogs_protocol.h/cpp` | **DELETE** — replaced by COBS proto.c extensions |
| `status_led.h/cpp` | Merge into NeoPixel code in main.cpp |

### motor_pwm.cpp refactor (2-pin A4950 mode)

```cpp
// OLD (TB6642FG with separate PWM pin):
//   IN1=direction, IN2=direction, PWM=speed
//
// NEW (A4950 — PWM on the active IN pin):
//   Forward: IN1=PWM(duty), IN2=LOW
//   Reverse: IN1=LOW, IN2=PWM(duty)
//   Coast:   IN1=LOW, IN2=LOW

class MotorPwm {
public:
  MotorPwm(uint in1_gpio, uint in2_gpio);  // no pwm_gpio param
  void init(uint32_t pwm_hz);
  void set(float duty);  // -1..1, sign=direction
  void stop();
private:
  uint in1_gpio_, in2_gpio_;
  uint in1_slice_, in1_chan_;
  uint in2_slice_, in2_chan_;
  uint16_t pwm_wrap_;
};
```

Both IN1 and IN2 are configured as PWM outputs at init. To drive forward,
set IN1 duty to desired level and IN2 duty to 0. Vice versa for reverse.
No GPIO function switching needed — just set PWM levels.

### config.h changes

Replace pin defines with combined map. Add motor + encoder + IMU pins:

```c
// ---- Motor drivers (A4950) ----
#define AZ_PIN_IN1       2
#define AZ_PIN_IN2       3
#define EL_PIN_IN1      23
#define EL_PIN_IN2      24

// ---- Encoders ----
#define AZ_PIN_ENC_A    14
#define AZ_PIN_ENC_B    15
#define EL_PIN_ENC_A    21
#define EL_PIN_ENC_B    22

// ---- ADXL345 IMU (shared SPI0 bus) ----
#define IMU_SPI_INST    spi0
#define IMU_PIN_CS      26
// SCK/MOSI/MISO shared with VHF: GP18/19/16

// ---- Motor config ----
#define MOTOR_PWM_HZ    20000
#define PID_HZ          100
```

### proto.h / proto.c extensions (new motor messages)

Add to msg_type_t enum:

```c
// Motor control extension (0x60-0x6F)
MSG_SET_POSITION    = 0x60,  // body: [az_f32_le, el_f32_le]
MSG_GET_POSITION    = 0x61,  // body: empty → rsp: [az_f32, el_f32]
MSG_PARK            = 0x62,  // body: empty
MSG_STOP            = 0x63,  // body: empty
MSG_HOME            = 0x64,  // body: empty → trigger IMU homing
MSG_GET_MOTOR_STATUS= 0x65,  // rsp: [state, faults, homed, az_f32, el_f32]
MSG_SET_GAINS       = 0x66,  // body: [kp_f32, ki_f32, kd_f32]
MSG_ZERO_ENCODERS   = 0x67,  // body: empty
MSG_IMU_READ        = 0x68,  // rsp: [x_f32, y_f32, z_f32, el_deg_f32]
MSG_RECAL           = 0x69,  // re-read IMU, re-zero EL

// Motor events
EVT_POSITION        = 0xE2,  // async 10Hz: [az_f32, el_f32, status_u8]
```

### main.cpp changes

```
setup():
  1. NeoPixel + buzzer init (unchanged)
  2. UART0 init (unchanged)
  3. UHF CC1200 init on SPI1 (unchanged)
  4. ADXL345 init on SPI0 (mode 3, 1 MHz)
  5. EL IMU homing loop (blocking, ~15s max)
  6. Reconfigure SPI0 → mode 0, 5 MHz
  7. VHF CC1200 init on SPI0 (now in correct mode)
  8. Motor PWM init (A4950 IN1/IN2 on new pins)
  9. Encoder ISR init (quadrature on GP14/15, GP21/22)
  10. Proto init with motor + radio

loop():
  // 100 Hz motor tick (10ms period)
  if (time_since_last_tick >= 10000us) {
    rotator.tick();  // PID + motor update
    last_tick = now;
  }

  // Existing RF HAT loop body:
  watchdog_update();
  buzzer_tick();
  proto_poll();      // handles both CC1200 + motor commands
  usb_serial_feed();

  // 10 Hz position event stream (if enabled)
  if (position_streaming && time_since_last_pos >= 100ms) {
    send EVT_POSITION with current az/el
  }

  delay(1);  // yield
```

### SPI0 mode switch helper

```c
static void spi0_set_mode(uint8_t cpol, uint8_t cpha, uint32_t baud) {
    spi_deinit(spi0);
    spi_init(spi0, baud);
    spi_set_format(spi0, 8, (spi_cpol_t)cpol, (spi_cpha_t)cpha, SPI_MSB_FIRST);
    // Re-set pin functions (they get cleared on deinit)
    gpio_set_function(VHF_PIN_SCK,  GPIO_FUNC_SPI);
    gpio_set_function(VHF_PIN_MOSI, GPIO_FUNC_SPI);
    gpio_set_function(VHF_PIN_MISO, GPIO_FUNC_SPI);
}

// Usage:
spi0_set_mode(1, 1, 1000000);  // mode 3, 1 MHz → ADXL345
spi0_set_mode(0, 0, 5000000);  // mode 0, 5 MHz → VHF CC1200
```

---

## Pi-Side Software Changes

### rf_hat.py → pico_link.py

Extend CC1200Link class with motor control methods:

```python
class PicoLink(CC1200Link):
    # Existing CC1200 methods stay unchanged

    def set_position(self, az_deg, el_deg):
        body = struct.pack('<ff', az_deg, el_deg)
        return self._command(MSG_SET_POSITION, body)

    def get_position(self):
        rsp = self._command(MSG_GET_POSITION)
        az, el = struct.unpack('<ff', rsp.body)
        return az, el

    def park(self):
        return self._command(MSG_PARK)

    def stop(self):
        return self._command(MSG_STOP)

    def home(self):
        return self._command(MSG_HOME)

    def zero_encoders(self):
        return self._command(MSG_ZERO_ENCODERS)
```

### station.py changes

Replace RotctlClient (TCP to rotctld) with PicoLink (direct UART):

```python
# OLD:
rotctl = RotctlClient('localhost', 4533)
rotctl.set_position(az, el)

# NEW:
link = PicoLink('/dev/serial0', 115200)
link.set_position(az, el)
link.set_frequency(doppler_hz)  # same link, same UART
```

### Eliminate rotctld.service

Remove from Pi/services/. The Pico handles motor control directly.
Optional: keep a lightweight TCP bridge in station.py for hamlib compat.

### dashboard.py

No changes — already reads ~/.station_status.json for status display.

---

## PCB Layout Considerations

### EMI zoning (critical)

```
 ┌─────────────────────────────────────────────────┐
 │  MOTOR ZONE              │   RF ZONE            │
 │                          │                      │
 │  A4950 (AZ)    ENCODER   │   CC1200    SMA_UHF  │
 │  A4950 (EL)    CONNS     │   (UHF)              │
 │                          │                      │
 │  24V bulk      MOTOR     │   CC1200    SMA_VHF  │
 │  caps          CONNS     │   (VHF)              │
 │                          │                      │
 │  ─ ─ ─ ─ PICO MODULE ─ ─ ─ ─ ─ ─ ─ ─ ─ ─ ─ ─ │
 │                                                 │
 │            PI 40-PIN HEADER                     │
 └─────────────────────────────────────────────────┘
```

- Solid ground plane (In1.Cu) under entire RF zone — NO motor traces crossing
- Motor 24V traces on opposite side from RF matching networks
- Ferrite bead + LC filter between motor 24V and buck 24V input
- Motor connector placement: board edge, far from SMA connectors
- A4950 thermal pads need ground pour vias for heat dissipation

### 6-layer stackup (JLCPCB, unchanged)

F.Cu / prepreg / In1.Cu (GND) / core / In2.Cu (PWR) / prepreg /
In3.Cu (PWR) / core / In4.Cu (GND) / prepreg / B.Cu

### Board size

Pi HAT form factor (85×56mm). Tight but feasible:
- Pico module: 51×21mm (dominant component)
- 2x A4950 SOIC-8: 2× (5×4mm) = small
- ADXL345 LGA-14: 5×3mm = tiny
- Motor/encoder connectors: 4x JST-XH on board edge

---

## BOM Delta vs Current RF_HAT

| Change | Part | Qty | LCSC |
|---|---|-----|---|
| ADD | A4950ELJTR-T (motor driver) | 2 | C82404 |
| ADD | ADXL345BCCZ (IMU) | 1 | C12563 |
| ADD | 100nF 50V 0402 (A4950 bypass) | 4 | basic |
| ADD | 10µF 50V 0805 (A4950 bulk) | 2 | basic |
| ADD | 100µF 50V electrolytic (24V bulk) | 1 | — |
| ADD | Ferrite 600Ω@100MHz 0805 (motor isolation) | 1 | basic |
| ADD | JST-XH 2-pin (motor conn) | 2 | — |
| ADD | JST-XH 4-pin (encoder conn) | 2 | — |
| ADD | 10k 0402 (IMU CS pull-up) | 1 | basic |
| ADD | 100nF + 10µF (IMU bypass) | 2 | basic |
| REMOVE | LMR51420 (second buck) | -1 | — |
| REMOVE | Buck passives (2nd) | -~8 | — |
| KEEP | Everything else from RF_HAT | — | — |

**Net add: ~15 components. Net remove: ~9. Delta: +6 components.**

---

## Repo Structure

New firmware directory: `Firmware/rp2040-motor-rf-hat/`

```
Firmware/rp2040-motor-rf-hat/
├── platformio.ini
├── src/
│   ├── main.cpp          (merged: RF HAT main + rotator init/loop)
│   ├── config.h          (combined pin map)
│   ├── proto.h/c         (extended with motor messages 0x60-0x69)
│   ├── cc1200.h/c        (unchanged from rf-hat)
│   ├── cobs.h/c          (unchanged)
│   ├── crc16.h/c         (unchanged)
│   ├── motor_pwm.h/cpp   (refactored: 2-pin A4950)
│   ├── quadrature.h/cpp  (from rotator, new pin numbers)
│   ├── rotator.h/cpp     (from rotator, unchanged logic)
│   └── adxl345.h/cpp     (from rotator, SPI mode switch added)
└── copy_uf2.py
```

KiCad project stays in `RF_HAT/` — update `rf_hat_circuit.py` to add
motor driver section. Output still goes to `RF_HAT_out/`.

Old firmwares (`rp2040-satnogs-rotator/`, `rp2040-rf-hat/`) remain for
reference and fallback to 2-board architecture.

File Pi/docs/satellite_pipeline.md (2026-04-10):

# Satellite Data Pipeline — How Sats Get On Screen

## Overview

```
CelesTrak/AMSAT TLE → PyEphem pass prediction → SatNOGS DB transmitter lookup → filtering → dashboard
```

## Step 1: TLE Acquisition

**Sources (priority order):**
1. Dashboard cache (`~/.station_tles.json`) — shared, <2h old
2. AMSAT (`amsat.org/tle/current/nasabare.txt`) — primary, reliable
3. CelesTrak — fallback (amateur, weather, NOAA, stations)

**station.py** checks dashboard cache first (avoids API thrashing), falls back to AMSAT + CelesTrak if stale (>30 min).

## Step 2: Pass Prediction

- `find_passes(tles, hours=12)` uses PyEphem
- Filter: minimum 5deg elevation, >10s duration
- Returns: `rise_time`, `set_time`, `max_el`, `rise_az`, `set_az`, `duration`
- Dashboard computes trajectory (10 points for sky plot)

## Step 3: Transmitter Enrichment

### SatNOGS DB API (`dashboard.py`)
- Endpoint: `https://db.satnogs.org/api/transmitters/?format=json&status=active`
- **Server-side filters:**
  - `type` in {`Transmitter`, `Transceiver`} — excludes Receiver (uplink-only)
  - Frequency: 420-450 MHz (UHF) or 130-175 MHz (VHF)
  - `alive=true`
- **Cache:** 12 hours
- **CRITICAL: If no transmitter found for a satellite, it is DROPPED from the pass list entirely**

### Per-satellite transmitter data:
```json
{
  "freq_mhz": 437.250,
  "mode": "GMSK",
  "baud": 9600,
  "band": "UHF",
  "cc1200_ok": true,
  "rtlsdr_ok": true,
  "description": "Mode U - 9k6 GMSK"
}
```

### Recently Heard Activity (background fetch)
- Endpoint: `network.satnogs.org/api/observations/?vetted_status=good&...`
- Provides: `last_heard_days`, `obs_count_30d`, `activity_score`
- Cache: disk (`~/.satnogs_cache/recently_heard.json`) + RAM (1h TTL)

### Local Profiles (`sat_profiles.json`)
- 10 known satellites with hand-tuned modulation params
- **Checked FIRST** — overrides SatNOGS DB data
- Contains: freq, modulation format, symbol rate, deviation, bandwidth, sync word
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

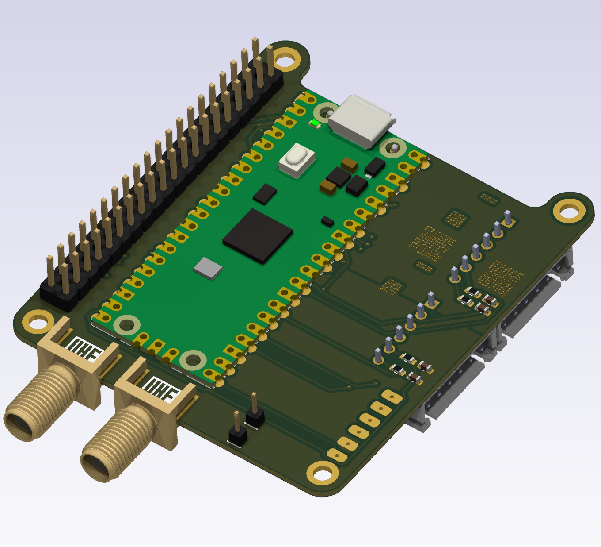
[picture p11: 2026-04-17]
ThesisPaper/images/photos/rf_hat_motor_back.png

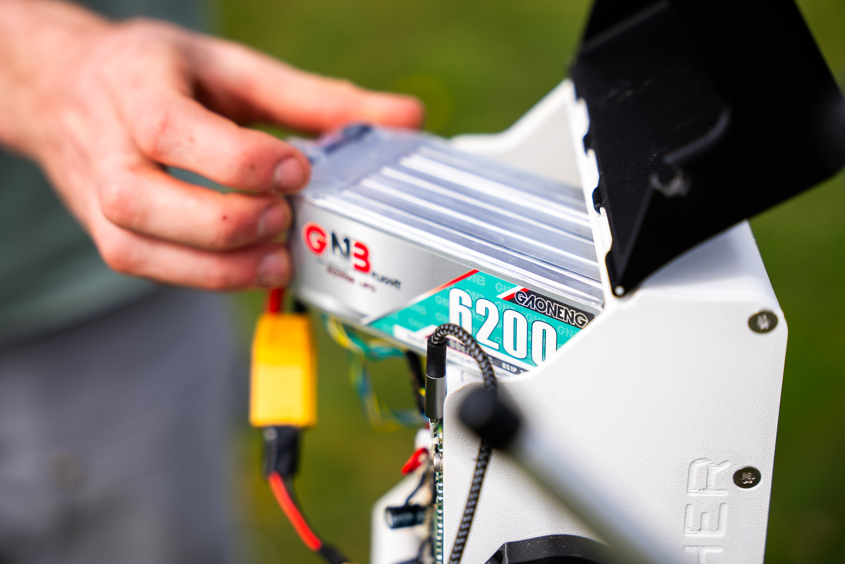
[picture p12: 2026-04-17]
ThesisPaper/images/photos/battery.jpg

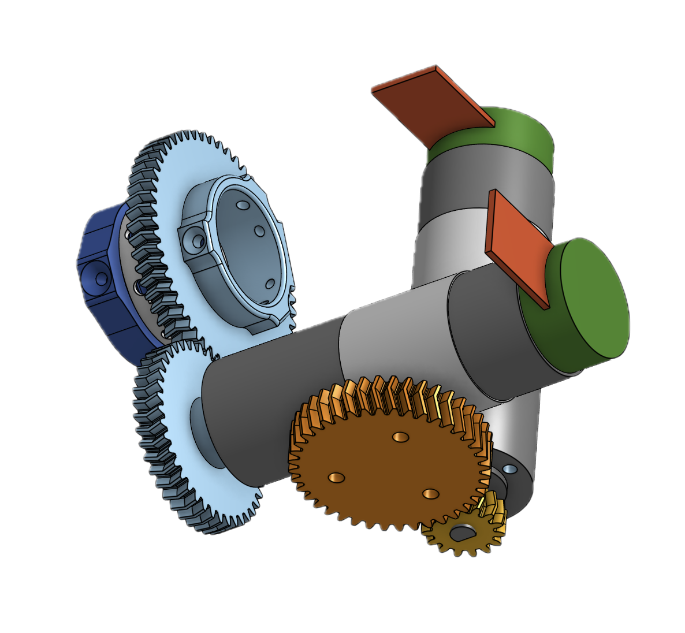
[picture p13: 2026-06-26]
ThesisPaper/images/photos/3DP_gears_all.png

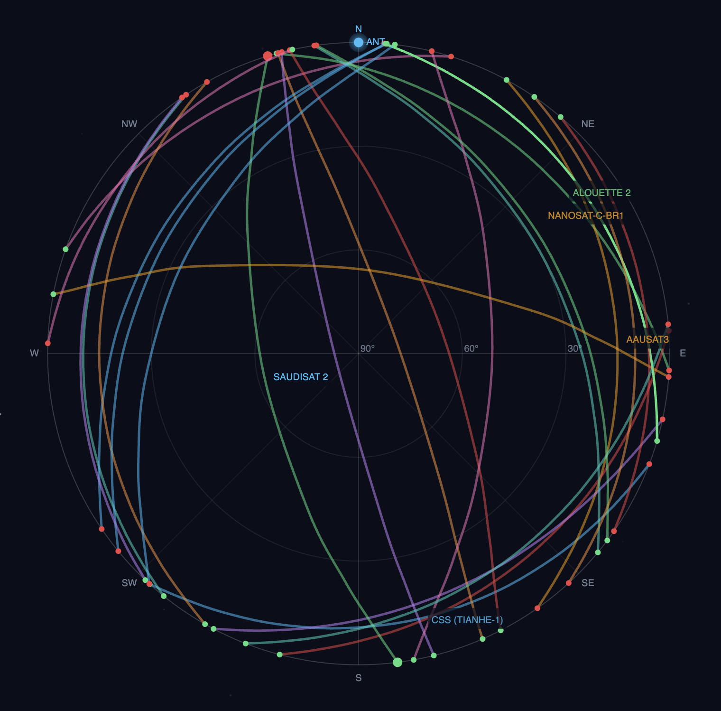
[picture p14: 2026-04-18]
ThesisPaper/images/skyplot.png

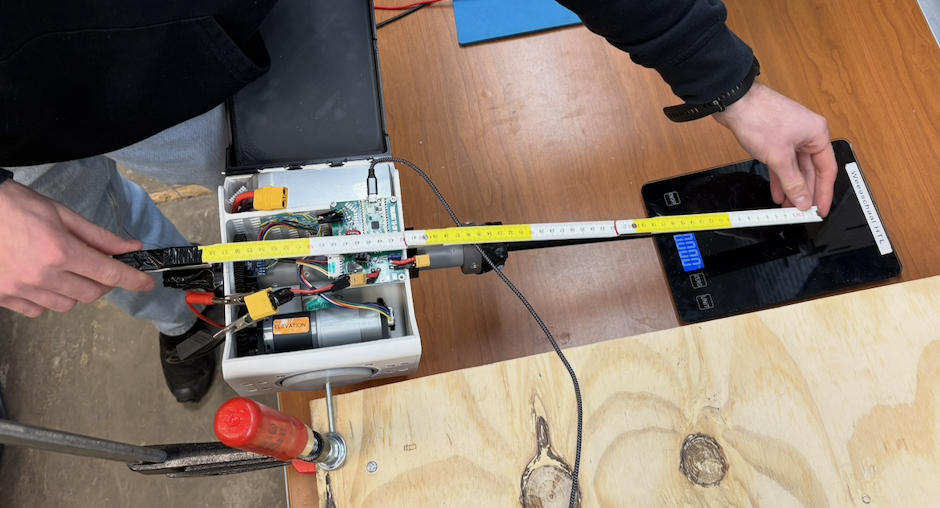
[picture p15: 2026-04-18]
ThesisPaper/images/photos/torque_el_arm.png

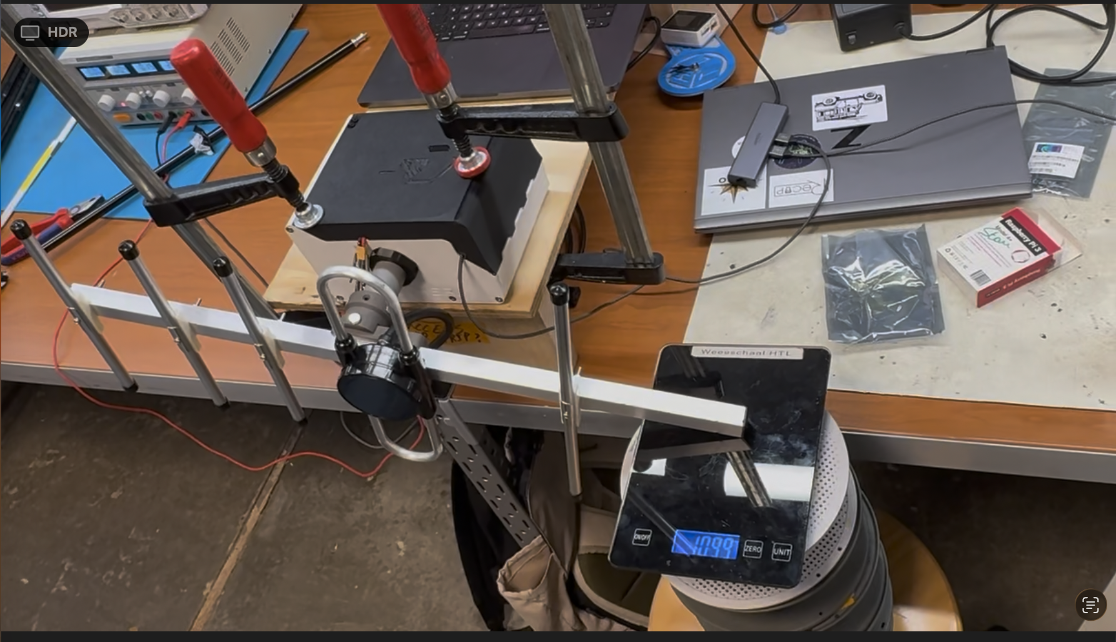
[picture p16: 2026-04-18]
ThesisPaper/images/photos/torque_az_scale.png

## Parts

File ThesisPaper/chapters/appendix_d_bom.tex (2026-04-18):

% ══════════════════════════════════════════════════════════════════════════════
\chapter{Detailed Bill of Materials}
\label{app:bom}
% ══════════════════════════════════════════════════════════════════════════════

The BOM below costs the \textbf{v2 combined MOTOR\_RF\_HAT} (design-complete, routed, ready to order, not yet fabricated at the time of submission). Field validation used the v1 two-board setup (separate MotorPCB + RF HAT), which was more expensive because each board was ordered separately and the RF HAT uses a 6-layer stackup. The lessons from v1 bring-up (\S\ref{sec:bringup}) are incorporated into the v2 BOM: A4950 replaces TB6642FG for availability, and four 100\,$\Omega$ series resistors (R11--R14) protect the A4950 logic inputs from GPIO transients. The off-board rotator BOM (motors, gears, bearings, chassis, fasteners) is unchanged from v1.

Component prices from the LCSC BOM tool (April 2026), hand-assembled. Full machine-readable BOM in \file{ThesisPaper/bom\_complete.csv}.

\section*{D.1 \ MOTOR\_RF\_HAT PCB: on-board components}

125 placed components (excluding test pads and mounting holes), 48 unique LCSC line items.

\begin{table}[H]
    \centering
    \begin{tabularx}{\textwidth}{lXrr}
        \toprule
        Category & Key components & Qty & LCSC total (\euro{}) \\
        \midrule
        Capacitors & 19 values (0603/0805/1206), CC1200 matching + bypass & 71 & 7.41 \\
        Inductors & 11 values (0603 RF + 3030 power), CC1200 matching & 17 & 1.18 \\
        Resistors & 7 values (0603) & 14 & 0.07 \\
        CC1200RHBR & UHF + VHF transceivers (C122881) & 2 & 4.43 \\
        A4950ELJTR-T & Motor drivers AZ + EL (C82404) & 2 & 1.10 \\
        LMR51420YFDDCR & 24~V $\to$ 5~V buck (C7296200) & 1 & 0.84 \\
        WS2812B-2020 & Status LEDs (C965555) & 4 & 0.28 \\
        40~MHz crystal & CC1200 reference (C5380316) & 2 & 0.12 \\
        BSS138 & Level shifter (C112239) & 1 & 0.01 \\
        1N4148WS & Protection diode (C2128) & 1 & 0.01 \\
        D\_Schottky & Buck diode (C3759853) & 1 & 0.14 \\
        XT30PW-M & 24~V power input (C431092) & 1 & 0.24 \\
        2$\times$20 Pi header & GPIO (C50980) & 1 & 0.14 \\
        JST XH 6-pin & Motor/encoder connectors (C157919) & 2 & 0.33 \\
        \midrule
        Visible line-item sum & & & 16.30 \\
        MOQ rounding uplift & (reels of 100 for 1--8-piece needs) & & 12.14 \\
        \textbf{LCSC subtotal} & & & \textbf{28.44} \\
        \bottomrule
    \end{tabularx}
    \caption{MOTOR\_RF\_HAT on-board component cost breakdown.}
\end{table}

Items sourced outside the default LCSC reflow batch (hand-soldered or not stocked at LCSC):

\begin{table}[H]
    \centering
    \begin{tabular}{llrr}
        \toprule
        Component & LCSC~\# & Qty & \euro{} \\
        \midrule
        SMA edge-mount connector & (not on LCSC) & 2 & 1.50 \\
        15~nH 0603 inductor & C23651 & 2 & 0.50 \\
        Raspberry Pi Pico (hand-soldered) & C7203002 & 1 & 4.00 \\
        \midrule
        \textbf{Subtotal} & & & \textbf{6.00} \\
        \bottomrule
    \end{tabular}
    \caption{Hand-soldered / off-batch items.}
\end{table}

\section*{D.2 \ PCB fabrication}

\begin{table}[H]
    \centering
    \begin{tabular}{lr}
        \toprule
        Item & \euro{} \\
        \midrule
        Bare PCB (6-layer, JLCPCB, per board from 5-piece order) & 6.00 \\
        \bottomrule
    \end{tabular}
    \caption{PCB fabrication cost (per board).}
\end{table}

\section*{D.3 \ Off-board components}

\begin{table}[H]
    \centering
    \begin{tabular}{llrr}
        \toprule
        Component & Source & Qty & \euro{} \\
        \midrule
        FAPG36-555-EN motor (24~V, 516:1) & AliExpress & 2 & 16.00 (line) \\
        Raspberry Pi 3 Model A+ & RPi distributor & 1 & 25.00 \\
        ASA filament ($\sim$400~g) & local & 1 & 10.00 \\
        Steel balls 3~mm (50~pcs) & AliExpress & 1 & 2.00 \\
        M4$\times$10 + M3$\times$8 screws, heat-set inserts & local & lot & 3.00 \\
        PVC pipe + misc hardware & local & lot & 2.00 \\
        ADXL345 IMU breakout & AliExpress & 1 & 1.50 \\
        \midrule
        \textbf{Off-board subtotal} & & & \textbf{59.50} \\
        \bottomrule
    \end{tabular}
    \caption{Off-board mechanical and computing components.}
\end{table}

\section*{D.4 \ Grand total}

\begin{table}[H]
    \centering
    \begin{tabular}{lr}
        \toprule
        Subsystem & \euro{} \\
        \midrule
        MOTOR\_RF\_HAT components (LCSC) & 28.44 \\
        Hand-soldered parts (SMA, 15~nH, Pico) & 6.00 \\
        Bare PCB (6-layer) & 6.00 \\
        Off-board components & 59.50 \\
        \midrule
        \textbf{Grand total per station core} & \textbf{$\sim$€100} \\
        \bottomrule
    \end{tabular}
    \caption{v2 grand-total cost (station core, excluding antenna, coax, power supply, and tripod).}
\end{table}

Excludes antenna, coax cable, 24~V power supply, and tripod (user-supplied). Hand-assembled, so no JLCPCB PCBA fees. LCSC total includes MOQ rounding (buying 100 passives when 1--8 are needed). The combined MOTOR\_RF\_HAT board eliminates the separate motor controller PCB and USB cable between Pi and rotator used in v1 testing. Numbers are projections for the unfabricated v2 board.

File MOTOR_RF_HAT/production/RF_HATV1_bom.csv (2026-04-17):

Designator | Footprint | Quantity | Value | LCSC Part #
C1 | 1206 | 1 | 4.7uF 50v | C98192
C10, C12, C16, C23, C48, C52, C8, C9 | 0603 | 8 | 15pF | C1644
C11 | 0603 | 1 | 1.8nF | C343008
C13 | 0603 | 1 | 1.5nF | C76600
C14, C15, C17, C18, C19, C20, C22, C25, C26, C27, C29, C30, C32, C34, C35, C38, C40, C42, C43, C46, C50, C53 | 0603 | 22 | 47nF | C1622
C2 | 0603 | 1 | 100n | C76939
C21, C31, C41, C51 | 0603 | 4 | 10nF | C57112
C24, C33, C57 | 0603 | 3 | 5.1pF | C61816
C28, C36, C4, C5, C6, C7 | 0603 | 6 | 220nF | C21120
C3 | 0805 | 1 | 22uF | C2762594
C37, C39, C44, C54, C56, C68, C69, C70, C71 | 0603 | 9 | 100pF | C14858
C45 | 0603 | 1 | 1.5pF | C695130
C47 | 0603 | 1 | 56pF | C338104
C49 | 0603 | 1 | 39pF | C445758
C55 | 0603 | 1 | 2.2pF | C1651
C58 | 0603 | 1 | 6.2pF | C48579262
C59 | 0603 | 1 | 1nF | C342910
C60, C61, C62, C64, C65, C66 | 0805 | 6 | 10uF | C19702
C63, C67 | 0603 | 2 | 100nF | C14663
D1 | 0603 | 1 | D_Schottky | C3759853
D2, D4, D5, D6 | LED_WS2812B-2020_PLCC4_2.0x2.0mm | 4 | WS2812B-2020 | C965555
D3 | D_SOD-323 | 1 | 1N4148WS | C2128
J1, J2 | PinHeader_1x01_P2.00mm_Vertical | 2 | Conn_01x01
J3 | PinHeader_2x20_P2.54mm_Vertical | 1 | Raspberry_Pi_2_3 | C50980
J4, J5 | SMA_Amphenol_132289_EdgeMount | 2 | SMA
J6 | CONN-TH_S6B-XH-A-LF-SN | 1 | JST_AZ | C157919
J7 | CONN-TH_S6B-XH-A-LF-SN | 1 | JST_EL | C157919
L1 | IND-SMD_L3.0-W3.0_AFE303020S | 1 | XRTC303020D4R7MBCA | C39846837
L10 | 0603 | 1 | 270nH | C668477
L11, L7 | 0603 | 2 | 56nH | C12831
L12, L17 | 0603 | 2 | 22nH | C98071
L13 | 0603 | 1 | 120nH | C307612
L14 | 0603 | 1 | 82nH | C98085
L15, L8 | 0603 | 2 | 15nH | C23651
L16 | 0603 | 1 | 43nH | C29683
L2, L3, L5 | 0603 | 3 | 100nH | C98089
L4 | 0603 | 1 | 47nH | C29683
L6, L9 | 0603 | 2 | 27nH | C162550
Q1 | SOT-23 | 1 | BSS138 | C112239
R1 | 0603 | 1 | 100k | C270364
R10 | 0603 | 1 | 18R | C245924
R11, R12, R13, R14 | 0603 | 4 | 100R | C22775
R2 | 0603 | 1 | 13.7k | C138175
R3, R4, R5, R7 | 0603 | 4 | 10k | C25804
R6, R8 | 0603 | 2 | 56k | C23206
R9 | 0603 | 1 | 22R | C23345
TP1 | smallpad | 1 | MISO
TP2 | smallpad | 1 | MOSI
TP3 | smallpad | 1 | CLK
TP4 | smallpad | 1 | CS
TP5 | smallpad | 1 | 3.3V
TP6 | smallpad | 1 | GND
U1 | AMASS_XT30PW-M_1x02_P2.50mm_Horizontal | 1 | XT30PW-M | C431092
U2 | SOT-23-6_L2.9-W1.6-P0.95-LS2.9-BL | 1 | LMR51420YFDDCR | C7296200
U3, U5 | QFN-32-1EP_5x5mm_P0.5mm_EP3.45x3.45mm | 2 | CC1200RHBR | C122881
U4 | RaspberryPi_Pico_SMD | 1 | RaspberryPi_Pico | C7203002
U6, U7 | SOIC-8-1EP_3.9x4.9mm_P1.27mm_EP2.41x3.3mm | 2 | A4950E | C82404
Y1, Y2 | Crystal_SMD_3225-4Pin_3.2x2.5mm | 2 | 40MHz | C5380316

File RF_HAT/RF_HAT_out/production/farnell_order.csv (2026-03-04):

Farnell Order Code | Quantity | Description
1813415 | 2 | 2.2pF 0603 C0G (C1)
1414601 | 2 | 39pF 0603 C0G KEMET (C2)
2904766 | 6 | 5.1pF 0603 (C3/C8/C9)
1572627 | 2 | 56pF 0603 (C5)
1759022 | 8 | 10nF 0603 (C6/C16/C31/C41)
1414603 | 10 | 100pF 0603 C0G KEMET (C7/C38/C39/C43/C47)
2496882 | 2 | 1nF 0603 (C10)
721980 | 16 | 15pF 0603 (C11-13/C20/C27/C32/C45-46)
1414643 | 44 | 47nF 0603 X7R KEMET (C14/C15/C21/C25-26/C28-30/C33/C35-37/C40/C42/C57-64)
1828900 | 12 | 220nF 0603 (C17/C34/C48-51)
2672137 | 2 | 1.5nF 0603 (C18)
1735545 | 2 | 4.7uF 50V 0805 (C19)
1650835 | 2 | 100nF 0603 (C22)
1813422 | 2 | 1.8nF 0603 (C23)
2494232 | 2 | 22uF 6.3V 0603 X5R Murata (C24)
721864 | 2 | 1.5pF 0603 (C44)
1843687 | 2 | Schottky diode 0603 (D1)
2689965 | 2 | 1N4148WS SOD-323 buzzer flyback (D2)
1342651 | 4 | SMA edge-mount Multicomp MP-19-70-TGG 50ohm (J1/J2)
1515375 | 4 | 15nH 0603 (L1/L5)
3471521 | 2 | 43nH 0603 Murata LQW18AN43NG00D (L2)
1515382 | 4 | 22nH 0603 (L3/L14)
1711807 | 4 | 56nH 0603 Multicomp MCFT000092 (L4/L7)
1515383 | 4 | 27nH 0603 (L6/L8)
9528032 | 6 | 100nH 0603 (L9/L10/L12)
1515390 | 2 | 47nH 0603 (L11)
3471564 | 2 | 270nH 0603 (L13)
3678407 | 2 | 120nH 0603 (L15)
1515396 | 2 | 82nH 0603 (L16)
4142875 | 2 | 4.7uH 3030 power inductor (L18)
9845330 | 2 | BSS138 N-FET SOT-23 buzzer driver (Q1)
9238603 | 8 | 10k 0603 (R1/R2/R4/R5)
9238697 | 4 | 56k 0603 (R3/R7)
9238271 | 2 | 18R 0603 (R6)
9238280 | 2 | 22R 0603 (R8)
9238727 | 2 | 100k 0603 (R16)
2138429 | 2 | 13.7k 0603 (R17)
3643332 | 2 | Raspberry Pi Pico (U3)
2723242 | 4 | 40MHz crystal 3225 10pF Epson TSX-3225 (Y1/Y2)

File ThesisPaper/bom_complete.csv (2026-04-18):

Subsystem | Designator | Value | Qty | Footprint | LCSC | Unit_EUR | Line_EUR | Source | Notes
# ═══════════════════════════════════════════════════════════════════════════
# MOTOR_RF_HAT PCB — On-board components (LCSC BOM tool pricing | April 2026)
# ═══════════════════════════════════════════════════════════════════════════
# Capacitors
PCB | C1 | 4.7uF 50V | 1 | 1206 | C98192 | 0.018 | 0.18 | LCSC | MOQ 10
PCB | C8/C9/C10/C12/C16/C23/C48/C52 | 15pF | 8 | 0603 | C1644 | 0.005 | 0.48 | LCSC | MOQ 100
PCB | C11 | 1.8nF | 1 | 0603 | C343008 | 0.033 | 0.66 | LCSC | MOQ 20
PCB | C13 | 1.5nF | 1 | 0603 | C76600 | 0.018 | 0.18 | LCSC | MOQ 10
PCB | C14/C15/C17-C20/C22/C25-C27/C29/C30/C32/C34/C35/C38/C40/C42/C43/C46/C50/C53 | 47nF | 22 | 0603 | C1622 | 0.005 | 0.47 | LCSC | MOQ 100
PCB | C2 | 100nF | 1 | 0603 | C76939 | 0.003 | 0.34 | LCSC | MOQ 100
PCB | C21/C31/C41/C51 | 10nF | 4 | 0603 | C57112 | 0.003 | 0.29 | LCSC | MOQ 100
PCB | C24/C33/C57 | 5.1pF | 3 | 0603 | C61816 | 0.003 | 0.30 | LCSC | MOQ 100
PCB | C3 | 22uF | 1 | 0805 | C2762594 | 0.041 | 0.20 | LCSC | MOQ 5
PCB | C4/C5/C6/C7/C28/C36 | 220nF | 6 | 0603 | C21120 | 0.007 | 0.66 | LCSC | MOQ 100
PCB | C37/C39/C44/C54/C56/C68-C71 | 100pF | 9 | 0603 | C14858 | 0.004 | 0.35 | LCSC | MOQ 100
PCB | C45 | 1.5pF | 1 | 0603 | C695130 | 0.015 | 0.77 | LCSC | MOQ 50
PCB | C47 | 56pF | 1 | 0603 | C338104 | 0.015 | 0.75 | LCSC | MOQ 50
PCB | C49 | 39pF | 1 | 0603 | C445758 | 0.015 | 0.75 | LCSC | MOQ 50
PCB | C55 | 2.2pF | 1 | 0603 | C1651 | 0.003 | 0.29 | LCSC | MOQ 100
PCB | C58 | 6.2pF | 1 | 0603 | C48579262 | 0.003 | 0.03 | LCSC
PCB | C59 | 1nF | 1 | 0603 | C342910 | 0.017 | 0.17 | LCSC
PCB | C60-C62/C64-C66 | 10uF | 6 | 0805 | C15850 | 0.008 | 0.10 | LCSC | MOQ 10
PCB | C63/C67 | 100nF | 2 | 0603 | C14663 | 0.004 | 0.04 | LCSC | MOQ 100
# Diodes & LEDs
PCB | D1 | Schottky | 1 | 0603 | C3759853 | 0.135 | 0.14 | LCSC
PCB | D2/D4/D5/D6 | WS2812B-2020 | 4 | 2020 | C965555 | 0.071 | 0.28 | LCSC
PCB | D3 | 1N4148WS | 1 | SOD-323 | C2128 | 0.007 | 0.01 | LCSC
# Connectors
PCB | J3 | 2x20 Pi header | 1 | 2.54mm | C50980 | 0.142 | 0.14 | LCSC
PCB | J4/J5 | SMA edge-mount | 2 | edge-mount | — | 0.75 | 1.50 | AliExpress | not on LCSC
PCB | J6/J7 | JST XH 6-pin | 2 | THT | C157919 | 0.166 | 0.33 | LCSC
# Inductors
PCB | L1 | 4.7uH power | 1 | 3030 | C39846837 | 0.145 | 0.15 | LCSC
PCB | L2/L3/L5 | 100nH | 3 | 0603 | C98089 | 0.032 | 0.10 | LCSC
PCB | L4 | 47nH | 1 | 0603 | C98076 | 0.010 | 0.01 | LCSC
PCB | L6/L9 | 27nH | 2 | 0603 | C162550 | 0.044 | 0.09 | LCSC
PCB | L7/L11 | 56nH | 2 | 0603 | C98079 | 0.010 | 0.02 | LCSC
PCB | L8/L15 | 15nH | 2 | 0603 | C23651 | 0.025 | 0.50 | LCSC | not found in BOM tool — estimate
PCB | L10 | 270nH | 1 | 0603 | C668477 | 0.075 | 0.08 | LCSC
PCB | L12/L17 | 22nH | 2 | 0603 | C98071 | 0.031 | 0.06 | LCSC
PCB | L13 | 120nH | 1 | 0603 | C307612 | 0.069 | 0.07 | LCSC
PCB | L14 | 82nH | 1 | 0603 | C98085 | 0.030 | 0.03 | LCSC
PCB | L16 | 43nH | 1 | 0603 | C113126 | 0.010 | 0.01 | LCSC
# MOSFET
PCB | Q1 | BSS138 | 1 | SOT-23 | C112239 | 0.014 | 0.01 | LCSC
# Resistors
PCB | R1 | 100k | 1 | 0603 | C270364 | 0.001 | 0.01 | LCSC
PCB | R2 | 13.7k | 1 | 0603 | C138175 | 0.001 | 0.01 | LCSC
PCB | R3/R4/R5/R7 | 10k | 4 | 0603 | C25804 | 0.001 | 0.01 | LCSC
PCB | R6/R8 | 56k | 2 | 0603 | C23206 | 0.001 | 0.01 | LCSC
PCB | R9 | 22R | 1 | 0603 | C23345 | 0.001 | 0.01 | LCSC
PCB | R10 | 18R | 1 | 0603 | C245924 | 0.001 | 0.01 | LCSC
PCB | R11-R14 | 100R | 4 | 0603 | C22775 | 0.001 | 0.01 | LCSC
# ICs
PCB | U1 | XT30PW-M | 1 | AMASS | C431092 | 0.239 | 0.24 | LCSC
PCB | U2 | LMR51420YFDDCR | 1 | SOT-23-6 | C7296200 | 0.837 | 0.84 | LCSC
PCB | U3/U5 | CC1200RHBR | 2 | QFN-32 | C122881 | 2.217 | 4.43 | LCSC
PCB | U4 | Raspberry Pi Pico | 1 | SMD module | — | 4.000 | 4.00 | RPi distributor | hand-soldered
PCB | U6/U7 | A4950ELJTR-T | 2 | SOIC-8-EP | C82404 | 0.549 | 1.10 | LCSC
PCB | Y1/Y2 | 40MHz crystal | 2 | 3225 | C5380316 | 0.058 | 0.12 | LCSC
# ═══════════════════════════════════════════════════════════════════════════
# PCB subtotals
# Components (LCSC BOM tool): EUR 28.44 (incl. MOQ rounding)
# SMA + 15nH (not on LCSC): EUR 2.00
# Pi Pico: EUR 4.00
# Bare PCB (6-layer): EUR 6.00
# PCB TOTAL: EUR 40.44
# ═══════════════════════════════════════════════════════════════════════════
# Off-board components — per station
# ═══════════════════════════════════════════════════════════════════════════
Off-board | — | FAPG36-555-EN 24V DC motor 516:1 | 2 | — | — | 8.000 | 16.00 | AliExpress
Off-board | — | Raspberry Pi 3 Model A+ | 1 | — | — | 25.000 | 25.00 | RPi distributor
Off-board | — | ASA filament ~400g | 1 | — | — | 10.000 | 10.00 | local
Off-board | — | Steel balls 3mm (50 pcs) | 1 | — | — | 2.000 | 2.00 | AliExpress
Off-board | — | M4x10 + M3x8 screws + heat-set inserts | 1 | lot | — | 3.000 | 3.00 | local
Off-board | — | PVC pipe + misc hardware | 1 | lot | — | 2.000 | 2.00 | local
Off-board | — | ADXL345 IMU breakout | 1 | — | — | 1.500 | 1.50 | AliExpress
# Off-board TOTAL: EUR 59.50
# ═══════════════════════════════════════════════════════════════════════════
# GRAND TOTAL: EUR ~100
# ═══════════════════════════════════════════════════════════════════════════
# Notes:
# - LCSC component prices from BOM tool upload | April 2026
# - MOQ inflation included (buy 100 passives when 1 needed)
# - Hand-assembled | no JLCPCB PCBA fees
# - Bare PCB: 6-layer | JLCPCB | 5-pc order
# - Excludes: antenna | coax | 24V power supply | tripod (user-supplied)
# - 3 items backordered on LCSC at time of lookup
# - Combined MOTOR_RF_HAT board (motor control + RF on single Pi HAT)

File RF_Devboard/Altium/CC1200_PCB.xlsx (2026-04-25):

Comment | Description | Designator | Quantity | Price | Total price | Supplier
GRM188D70J226ME01D | Multilayer Ceramic Capacitor 22uF 20% 6.3V X7T 0603 Paper T/R | C15, C16 | 5 | 0.284 | 1.42 | Mouser
GCJ188R71C103KA01D | Cap Ceramic 0.01uF 16V X7R 10% Pad SMD 0603 Soft Termination 125C Automotive T/R | C38 | 3 | 0.206 | 0.618 | Mouser
06035A5R1CAT2A | 0603 5.1 pF 50 V ±0.25 pF Tolerance C0G/NP0 Multilayer Ceramic Capacitor | C39, C48, C51 | 8 | 0.172 | 1.376 | Mouser
06035A560JAT2A | 0603 56 pF 50 V ±5% Tolerance C0G/NP0 Surface Mount Multilayer Ceramic Capacitor | C40 | 3 | 0.095 | 0.285 | Mouser
06035A101JAT2A | 0603 100 pF 50 V ±5% Tolerance C0G/NP0 SMT Multilayer Ceramic Capacitor | C41 | 3 | 0.095 | 0.285 | Mouser
06035A390JAT2A |  | C47 | 3 | 0.138 | 0.414 | Mouser
06035A6R2BAT2A |  | C49 | 3 | 0.533 | 1.599 | Mouser
06035A2R2CAT2A | 0603 2.2 pF 50 V ±0.25 pF Tolerance C0G/NP0 SMT Multilayer Ceramic Capacitor | C50 | 3 | 0.129 | 0.387 | Mouser
GCM188R71H152KA37D |  | C52 | 3 | 0.103 | 0.309 | Mouser
LSM0805463V | LED 0805 BLUE SMD | D1, D3, D4, D5, D7 | 12 | 0.255 | 3.06 | Mouser
SMBJ33A-13-F | TVS DIODE 33V 53.3V SMB | D2 | 3 | 0.181 | 0.543 | Mouser
150141M173100 |  | D6 | 2 | 0.43 | 0.86 | Mouser
BLM18HE601SN1D | Chip Ferrite Bead, 0603, 600Ω @ 100MHz, 0.25Ω, 25%, 800mA | FB1 | 2 | 0.181 | 0.362 | Mouser
USBLC6-2SC6 | Integrated Circuit | IC1 | 3 | 0.31 | 0.93 | Mouser
CC1200RHBR | Integrated Circuit | IC2 | 2 | 4.14 | 8.28 | Mouser
CON-SMA-EDGE-S | CONN SMA JACK STR EDGE MNT | J2 | 2 | 2.17 | 4.34 | Mouser
USB4105-GF-A-060 | USB Connector Type C SMT 12 Pin | J2 | 3 | 0.671 | 2.013 | Mouser
XFL4020-222MEC | INDUCTOR, 2.2UH, 8A, 20%, 38MHZ, REEL | L1 | 2 | 1.79 | 3.58 | Mouser
LQG18HN56NJ00D | Multilayer type RF Inductor 56nH ±5% 0.75Ω 400mA 0603 | L2, L3 | 4 | 0.12 | 0.48 | Mouser
LQG18HN27NJ00D | Multilayer type RF Inductor 27nH ±5% 0.54Ω 500mA 0603 | L4, L5 | 4 | 0.112 | 0.448 | Mouser
LQG18HN15NJ00D | Multilayer type RF Inductor 15nH ±5% 0.35Ω 600mA 0603 | L6, L9 | 4 | 0.12 | 0.48 | Mouser
0603DC-43NXJRW | Multilayer type RF Inductor 43nH ±5%0603 | L7 | 2 | 0.946 | 1.892 | Mouser
LQG18HN22NJ00D | Multilayer type RF Inductor 22nH ±5% 0.5Ω 500mA 0603 | L8 | 2 | 0.12 | 0.24 | Mouser
36906326S | 36906326S WE-SHC Shielding Cabinet | MP1 | 2 | 2.75 | 5.5 | Mouser
MMBT3904-7-F | TRANS NPN 40V 0.2A SMD SOT23-3 | Q2 | 3 | 0.103 | 0.309 | Mouser
JS102011SAQN | SWITCH SLIDE SPDT 300MA 6V | SW1 | 3 | 0.645 | 1.935 | Mouser
INA260AIPWR | IC MONITOR PWR/CURR 16TSSOP | U1 | 2 | 4.76 | 9.52 | Mouser
LT8609SIV#PBF | IC REG BUCK ADJUSTABLE 2A 16LQFN | U2 | 2 | 8.42 | 16.84 | Mouser
TPS7A2133PQWDRBRQ1 | Automotive, 500mA, low-noise ultra-low-IQ high-PSRR low-dropout (LDO) voltage regulator | U3, U5 | 4 | 0.731 | 2.924 | Mouser
TPS2113ADRBT | Dual In / Single Out Autoswitching Power Mux, 2.8 to 5.5 V, -40 to 85 degC, 9-pin SON (DRB), Green (RoHS & no Sb/Br) | U4 | 3 | 2.37 | 7.11 | Mouser
SC0914(7) | 32-Bit Dual-Core ARM Cortex-M0+ Microcontroller | U6 | 4 | 0.69 | 2.76 | Mouser
W25Q128JVSIQ | FLASH - NOR Memory IC 128Mb (16M x 8) SPI - Quad I/O, QPI, DTR 133 MHz 8-SOIC | U7 | 3 | 1.62 | 4.86 | Mouser
ABM8-272-T3 | 12 MHz Â±30ppm Crystal 10pF 50 Ohms 4-SMD, No Lead | Y1 | 3 | 0.99 | 2.97 | Mouser
NX3225SA-40.000MHZ-STD-CSR-1 NDK | Parallel - Fundamental Quartz Crystal, 40MHz Nom | Y2 | 3 | 0.929 | 2.787 | Mouser
 |  |  |  | Total | 91.716

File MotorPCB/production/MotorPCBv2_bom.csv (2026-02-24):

Designator | Footprint | Quantity | Value | LCSC Part #
C1, C13, C15, C2, C21, C26, C3, C4 | 0805 | 8 | 100nF
C10, C11, C12, C19, C22, C23, C24, C25 | 0805 | 8 | 10uF
C14 | 1206 | 1 | 4.7uF
J2 | CONN-TH_S6B-XH-A-LF-SN | 1 | JST_EL | C157919
J3 | CONN-TH_S2B-XH-A-LF-SN | 1 | END_AZ | C157931
J6 | CONN-TH_S6B-XH-A-LF-SN | 1 | JST_AZ | C157919
J7 | CONN-TH_S2B-XH-A-LF-SN | 1 | END_EL | C157931
L2 | L_Bourns-SRN4018 | 1 | 15uH
R1, R10, R11, R12, R6, R7, R8, R9 | 0805 | 8 | 10k
R13 | 0805 | 1 | 88.7k
R14 | 0805 | 1 | 22.1k
R2, R3, R4, R5 | 0805 | 4 | 100R
TP1, TP10, TP11, TP12, TP13, TP14, TP15, TP16, TP17, TP18, TP2, TP3, TP4, TP5, TP6, TP7, TP8, TP9 | smallpad | 18 | ~
U1, U3 | AMASS_XT30PW-M_1x02_P2.50mm_Horizontal | 2 | XT30PW-M | C431092
U2, U8 | HSOP-16_L13.5-W6.4-P1.00-LS9.6-BL-EP | 2 | TB6642FG,8,EL | C2150576
U5 | COMM-SMD_L51.0-W21.0-P2.54_SC0916 | 1 | PICO | C7203002
U6 | SOT-23-6_L2.9-W1.6-P0.95-LS2.8-BR | 1 | TPS560430XFDBVT | C2863641

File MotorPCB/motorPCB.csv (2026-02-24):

Id | Designator | Footprint | Quantity | Designation | Supplier and ref
1 | R11,R6,R9,R7,R1,R8,R10,R12 | R_0805_2012Metric_Pad1.20x1.40mm_HandSolder | 8 | 10k
2 | R5,R2,R4,R3 | R_0805_2012Metric_Pad1.20x1.40mm_HandSolder | 4 | 100R
3 | TP11,TP7,TP15,TP10,TP3,TP8,TP18,TP5,TP16,TP2,TP1,TP14,TP17,TP9,TP4,TP13,TP6,TP12 | smallpad | 18 | ~
4 | C26,C21,C3,C2,C15,C4,C13,C1 | C_0805_2012Metric_Pad1.18x1.45mm_HandSolder | 8 | 100nF
5 | C10,C24,C19,C11,C12,C23,C22,C25 | C_0805_2012Metric_Pad1.18x1.45mm_HandSolder | 8 | 10uF
6 | L2 | L_Bourns-SRN4018 | 1 | 15uH
7 | R14 | R_0805_2012Metric_Pad1.20x1.40mm_HandSolder | 1 | 22.1k
8 | J6 | CONN-TH_S6B-XH-A-LF-SN | 1 | JST_AZ
9 | U8,U2 | HSOP-16_L13.5-W6.4-P1.00-LS9.6-BL-EP | 2 | TB6642FG,8,EL
10 | J3 | CONN-TH_S2B-XH-A-LF-SN | 1 | END_AZ
11 | R13 | R_0805_2012Metric_Pad1.20x1.40mm_HandSolder | 1 | 88.7k
12 | U5 | COMM-SMD_L51.0-W21.0-P2.54_SC0916 | 1 | PICO
13 | J7 | CONN-TH_S2B-XH-A-LF-SN | 1 | END_EL
14 | J2 | CONN-TH_S6B-XH-A-LF-SN | 1 | JST_EL
15 | C14 | C_1206_3216Metric_Pad1.33x1.80mm_HandSolder | 1 | 4.7uF
16 | U1,U3 | AMASS_XT30PW-M_1x02_P2.50mm_Horizontal | 2 | XT30PW-M
17 | U6 | SOT-23-6_L2.9-W1.6-P0.95-LS2.8-BR | 1 | TPS560430XFDBVT

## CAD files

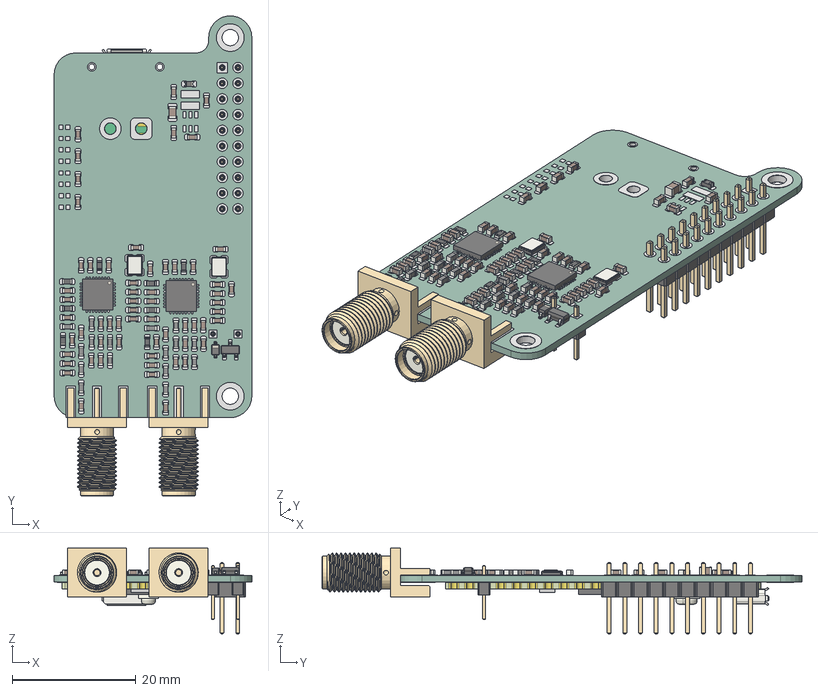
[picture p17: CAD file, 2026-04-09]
RF_HAT/RF_HAT_out/RF_HAT.step
32.0 x 77.6 x 13.9 mm
L_0603_1608Metric x 16
R_0603_1608Metric x 8
C_0603_1608Metric x 60
SMA_Amphenol_132289_EdgeMount x 2
QFN-32-1EP_5x5mm_P0.5mm_EP3.45x3.45mm x 2
Crystal_SMD_3225-4Pin_3.2x2.5mm x 2
SOT-23
D_SOD-323
C_0805_2012Metric
D_0603_1608Metric
PinHeader_2x10_P2.54mm_Vertical
PinHeader_1x01_P2.00mm_Vertical x 2
RaspberryPi_Pico_Module_KiCad
RF_HAT_pad
RF_HAT_PCB

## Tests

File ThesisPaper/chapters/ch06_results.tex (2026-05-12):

% ══════════════════════════════════════════════════════════════════════════════
\chapter{Results and Validation}
\label{ch:results}
% ══════════════════════════════════════════════════════════════════════════════

\section{Slew Speed}
\label{sec:slew-speed}

Slew speed was measured on a single axis, unloaded, at 24~V supply, by commanding the rotator to traverse 360\degree\ at a fixed PWM duty and timing the traverse with the onboard encoder tick counter. Four duty levels were tested. Raw data and per-run encoder-derived rates are listed in Appendix~\ref{app:pid}.

\begin{table}[H]
    \centering
    \begin{tabular}{lll}
        \toprule
        Duty (\%) & Speed (\degree/s) & 360\degree\ time (s) \\
        \midrule
        35 & 11.2 & 32.1 \\
        55 & 18.9 & 19.0 \\
        75 & 26.9 & 13.4 \\
        95 & 35.0 & 10.3 \\
        \bottomrule
    \end{tabular}
    \caption{Slew-speed measurements, unloaded, 24~V supply.}
\end{table}

Linear regression over the four measured points gives slope 0.40\degree/s per \% duty, $R^2 > 0.99$. 100\,\% duty was tested separately and trips the TB6642FG overcurrent protection on motor stall, so it is not included in the fit. The 35\degree/s ceiling at 95\,\% duty exceeds the total angular rate $\dot{\theta}_{\max} \approx 1.1$\degree/s derived in \S\ref{sec:orbital-mechanics} by a factor of approximately 32. It does not cover the instantaneous \textit{azimuth} rate during near-zenith passes (which can exceed 10\degree/s for a few seconds); \S\ref{sec:tracking-accuracy} reports the resulting AZ tracking error during such passes.

\section{PID Step Response}
\label{sec:pid-step}

With the deployed gains ($K_p = 0.15$, $K_i = 0.03$, $K_d = 0.02$, duty-filter $\alpha = 0.15$, max duty 0.95; \S\ref{sec:rotator-pid}) a 90\degree\ commanded step settles to within the 0.05\degree\ deadband in approximately 4~s, with overshoot below 0.5\degree. The settling time decomposes as: slew-limited traverse of 90\degree\ at 35\degree/s peak rate = $90/35 = 2.6$~s, plus roughly 1.4~s of final convergence through the duty output filter and deadband. The closed-loop bandwidth is bounded above by the duty-output filter time constant:
\begin{equation}
    \tau_\text{duty} = \frac{\Delta t}{\alpha} = \frac{0.01}{0.15} \approx 0.067~\text{s}, \qquad f_{-3\,\text{dB}} \approx \frac{1}{2\pi \tau} \approx 2.4~\text{Hz}.
\end{equation}

In practice the slew-rate limit sets the large-signal response time; the 2.4~Hz figure applies to small-signal tracking above the deadband. Either is well above the $\leq$1.1\degree/s total angular rate of a 400~km LEO pass (\S\ref{sec:orbital-mechanics}).

\begin{figure}[H]
    \centering
    
    \caption{PID step response for a 90\degree\ commanded step.}
\end{figure}

\section{Satellite Tracking Accuracy}
\label{sec:tracking-accuracy}

Tracking error was computed per pass from the CSV log (commanded AZ/EL from \code{station.py} pass predictor vs. actual encoder readback from the MotorPCB, sampled at 5~Hz; logs in \file{captures/20260409/pass\_logs/} and \file{captures/20260412/}). Absolute-value errors are binned by the satellite's peak-elevation category:

\begin{table}[H]
    \centering
    \begin{tabularx}{\textwidth}{lX}
        \toprule
        Scenario & Error ($|$commanded $-$ actual$|$) \\
        \midrule
        EL tracking, all passes & $<$0.5\degree\ throughout the pass \\
        AZ tracking, 20\degree--70\degree\ peak elevation & 0\degree--3\degree\ throughout the pass \\
        AZ tracking, peak elevation $>$70\degree\ (near-zenith) & 11\degree--166\degree\ during the $\sim$2--4~s zenith-crossing window; recovers to 0\degree--3\degree\ below 70\degree \\
        \bottomrule
    \end{tabularx}
    \caption{Tracking error binned by satellite peak elevation.}
\end{table}

Across passes with peak elevation in the 20\degree--70\degree\ band (the range where the Chapter~\ref{ch:background} link budget closes), both axes remain inside the Siretta Oscar 44 3-dB beamwidths (54\degree\ H-plane, 48\degree\ E-plane; \S\ref{sec:problem-statement}). The near-zenith AZ excursions exceed the 35\degree/s motor ceiling from \S\ref{sec:slew-speed} for a few seconds per pass; this is a speed-limit event, not an accuracy-limit one, and the error decreases monotonically as the satellite descends below 70\degree\ elevation.

\section{RF Devboard Validation}
\label{sec:rf-measurements}

Two devboards were connected to a host PC and exercised with \file{cc1200\_rf\_test.py}. The test script loads a bench validation SmartRF profile (2.4\,kbps 2-GFSK, 5.2\,kHz deviation, 10\,kHz channel filter; modulation index $h = 2\Delta f/f_b \approx 4.3$, chosen for robustness at short range rather than spectral efficiency, this is not the AetherSpace flight configuration, which remains to be defined once the satellite's modulation parameters are finalised), tunes both boards to a specified frequency, and runs a bidirectional packet exchange: Board\,A transmits a sequence of fixed-size payloads while Board\,B receives, then the roles are reversed. Payload matching is verified byte-for-byte.

The frequency sweep covered 430--439\,MHz in 1\,MHz steps with 50 packets per direction per frequency (1000 total). Test conditions: 1\,m board separation, dipole antennas, indoor lab, CRC-16 enabled. Table~\ref{tab:devboard-bench} shows the per-frequency results averaged over both directions.

\begin{table}[H]
    \centering
    \caption{Devboard bench test results per frequency, averaged over both directions (50 packets each). LQI lower~=~better.}
    \small
    \begin{tabular}{rrrrr}
        \toprule
        Freq (MHz) & RSSI avg (dBm) & LQI avg & Latency avg (ms) & Loss (\%) \\
        \midrule
        430 & $-$83.6$^\dagger$  & 0.4 & 103.5 & 0.0 \\
        431 & $-$103.7           & 0.3 & 103.3 & 0.0 \\
        432 & $-$102.4           & 0.5 & 103.3 & 0.0 \\
        433 & $-$103.6           & 0.4 & 104.1 & 0.0 \\
        434 & $-$103.7           & 0.4 & 104.0 & 0.0 \\
        435 & $-$88.8$^\dagger$  & 0.5 & 106.5 & 0.0 \\
        436 & $-$103.2           & 0.4 & 104.8 & 0.0 \\
        437 & $-$103.9           & 0.5 & 103.5 & 0.0 \\
        438 & $-$103.9           & 0.4 & 104.3 & 0.0 \\
        439 & $-$103.7           & 0.4 & 103.6 & 0.0 \\
        \bottomrule
        \multicolumn{5}{l}{\footnotesize $^\dagger$ Fractional-N PLL low-dither artefact; see text.}
    \end{tabular}
    \label{tab:devboard-bench}
\end{table}

Zero packet loss and 100\,\% payload match across all 10 frequencies confirm that the CC1200 SPI driver, SmartRF profile loading, COBS framing, TX and RX FIFO paths, sync-word detection, CRC validation, and bidirectional TRX switching all function correctly on the devboard hardware. LQI is a CC1200 demodulator quality metric that accumulates constellation error over 64 symbols after sync detection; lower values indicate smaller error. The uniform averages of 0.3--0.5 across all frequencies reflect near-perfect symbol recovery at short range, and confirm that neither the RSSI anomalies at 430 and 435\,MHz nor the noise-floor readings elsewhere affect demodulator performance. Latency averages of 103--107\,ms are consistent across the sweep, reflecting the end-to-end pipeline from host TX command through USB CDC, CC1200 transmission, and USB CDC return; the flat profile confirms no frequency-dependent timing effects.

The elevated RSSI at 430 and 435\,MHz is a measurement artefact rooted in the CC1200's fractional-N PLL. In a fractional-N synthesiser the divider ratio is not an exact integer, so a sigma-delta modulator continuously switches the divider between neighbouring integer values, a process called dithering, which spreads quantisation noise across a broad frequency range and produces typical phase-noise behaviour. At 430\,MHz the FREQ register evaluates to an exact integer multiple (\textsc{freq2}\,=\,\texttt{0x2B}, \textsc{freq1}\,=\,\textsc{freq0}\,=\,\texttt{0x00}), placing the synthesiser at a true integer-N boundary where the sigma-delta is idle and dithering does not occur. At 435\,MHz the fractional part is exactly one-half (\textsc{freq2}\,=\,\texttt{0x2B}, \textsc{freq1}\,=\,\texttt{0x80}, \textsc{freq0}\,=\,\texttt{0x00}), so the sigma-delta alternates between only two adjacent divider states rather than spanning a broader range; dithering is minimal rather than absent. Both conditions produce lower-than-typical local-oscillator phase noise, which, combined with the RSSI sample being taken immediately after packet reception before the running average has decayed to the ambient floor, produces the apparent peaks.

What the bench test does not establish is satellite reception, the bench test scopes the transceiver stack in isolation, not the system sensitivity in a satellite geometry.

\section{Field Deployment and Live-Pass Observations}
\label{sec:field-tests}

Three field sessions were conducted with the complete station on a camera tripod in an open field, powered from a bench supply via extension cord and using an iPhone hotspot for internet. Total setup time from unpacking to first tracked pass was approximately 4 minutes, with no SSH session or laptop-side configuration required beyond opening the dashboard in a browser.

\begin{figure}[H]
    \centering
    
    \caption{Wide shot of the deployed station in the field.}
\end{figure}

CSV pass logs (timestamp, commanded AZ/EL, encoder AZ/EL, RSSI, frequency, Doppler offset, slant range, packet count, 5~Hz cadence) were written to \file{captures/20260409/pass\_logs/} and \file{captures/20260412/}. Across all three sessions 210 passes were logged. The Doppler correction loop ran throughout: the observed $\pm$9~kHz sweep at 432~MHz is consistent with the $\pm$11~kHz maximum predicted in \S\ref{sec:doppler}, with the commanded offset clipped at the peak radial velocity the satellite actually reaches. The noise floor and reception outcome derived from these logs are reported in \S\ref{sec:packet-reception} and are not repeated here.

\subsection{Firmware bugs surfaced by live passes}

Four firmware/software defects were diagnosed during field sessions and fixed in the same session:

\begin{itemize}
    \item AZ integral windup after zenith crossing. When the AZ axis saturated during a high-rate zenith crossing, the PID integral accumulated a large error; after the satellite descended and the rate dropped, the integral fought the proportional term and oscillated. Fixed with the saturation-based anti-windup described in \S\ref{sec:rotator-pid}: the integral stops accumulating when $|u| \geq 0.95$ and the error sign would grow it further.
    \item Duty output filter too slow. The PWM output LPF at $\alpha = 0.05$ (time constant 0.2~s) made the AZ axis unresponsive at tracking rates below $\sim$1\degree/s. $\alpha$ was raised to 0.15 (0.067~s) with no observed increase in motor-current transients; this is the deployed setting used throughout \S\ref{sec:pid-step}.
    \item Doppler base-frequency compounding. A defect in \code{set\_frequency()} overwrote the per-satellite base frequency with the Doppler-corrected value, so each successive 2~Hz update accumulated on top of the last correction. Fixed by introducing a separate \code{uhf\_base\_freq\_hz} variable that holds the satellite's nominal frequency constant across the pass, with the Doppler offset applied only when writing the CC1200 FREQ/FREQOFF registers.
    \item Rotator socket timeout. The TCP \code{set\_position()} call to \code{rotctld} blocked up to 5~s on the receive side, limiting effective tracking rate. Reduced to 0.5~s with fire-and-forget sends, plus a 15~s keepalive ping during AOS wait to keep the socket responsive. Implementation in \code{station.py}.
\end{itemize}

\section{Packet Reception: Result and Interpretation}
\label{sec:packet-reception}

As of April 2026, no protocol-valid frames have been decoded from orbit. Across the three field sessions the station tracked approximately 210 satellite passes (16 on April 1 baseline with uncalibrated RSSI readout, 184 on April 9, and 10 on April 12) and captured tens of megabytes of raw binary data, but:

No CRC-16/CCITT-valid HDLC frames (with or without G3RUH descrambling), no AX.25 frames with valid FCS, no AX.100 Mode~5 frames passing Reed--Solomon RS(255,223) correction, and consequently no decoded packets submitted to the SatNOGS DB from real satellites.

The receive chain has been validated for local test frames in a short-range ground-to-ground configuration between two devboards (\S\ref{sec:rf-measurements}): transmitted test frames decode at the receiver with valid sync word and zero payload errors across all tested frequencies, exercising the RF path, SmartRF register set, FIFO drain, and host-side decoders under those conditions. This ground validation confirms the digital and RF path is internally consistent; it does not establish that the system is receiving orbital signals.

The April 1 session predates the RSSI-readout fix (AGC\_GAIN\_ADJUST calibration) and is used as the negative control in the analysis below; the April 9 and April 12 sessions use the post-fix calibration.

\subsection{Reception Modes Deployed}

Two RX modes were used, selected per satellite by \code{station.py} (\S\ref{sec:rf-hat-firmware}):

\begin{enumerate}
    \item FIFO mode (default): CC1200 matches a sync word (e.g. AX.100 ASM \code{0x930B51DE}), then delivers fixed-length 255-byte chunks. If sync or modulation parameters don't match, the FIFO drains receiver noise after false sync triggers.
    \item Serial mode with AX.25 G3RUH decode: for $\geq$4800~bps FSK, the firmware switches to PIO serial capture and the G3RUH / NRZ-I / HDLC pipeline of \S\ref{sec:serial-mode}. No CRC-valid AX.25 frames were recovered from orbital data.
\end{enumerate}

\subsection{Why no decoded frames}

The \S\ref{sec:link-budget} link budget shows the AetherSpace downlink is already marginal at the datasheet CC1200 sensitivity ($-$5.7~dB theoretical margin at 30\degree\ elevation). In the field, board-level interference raises the effective noise floor to $-$96~dBm, burying the received signal of $-$125.7~dBm approximately 30~dB below the detection threshold. CRC-16 is error detection, not correction; RS(255,223) cannot compensate for a deficit of that size. The zero-frame outcome is the predicted outcome.

Three factors contribute:

\begin{enumerate}
    \item \textbf{Front-end noise figure and board interference.} No LNA, so the CC1200 AGC operates on antenna noise plus on-board interference (LMR51420 buck harmonics, RP2040 digital, Pi GPIO/HDMI); measured noise floor sits approximately 30~dB above the expected kTB+NF limit at the CC1200 input.
    \item \textbf{Modulation parameter uncertainty.} The SatNOGS DB does not always publish exact symbol rate / deviation / sync word for non-AetherSpace satellites; any mismatch in FIFO mode produces zero output.
    \item \textbf{Link geometry.} A +14~dBm / +2~dBi CubeSat leaves negative theoretical margin at mid-elevation even with a perfect receiver.
\end{enumerate}

\subsection{What was observed: suggestive but not diagnostic}

The captures contain statistical patterns that are individually compatible with weak sub-threshold satellite reception, but each is also compatible with receiver noise or demodulator artefacts triggered by RF activity at the sync-word matcher. Both hypotheses are named explicitly below.

\paragraph{A. Elevation-binned mean RSSI (suggestive).} Grouping 62 tracked passes by peak elevation, mean peak RSSI increases monotonically by +4.2~dB from the 0--20\degree\ bin to the 60--90\degree\ bin. Weak satellite RF entering the front end at higher elevations is one possible explanation. However, the dataset is also confounded by pointing-dependent antenna temperature, local 433~MHz interference, AGC behaviour, and pass-selection effects; a passive antenna pointed at cold sky would normally lower the noise floor relative to the horizon, so this trend cannot be treated as proof of satellite reception without calibrated controls.

\paragraph{B. Cross-capture byte matching on SNUGLITE-II (suggestive, inconclusive).} Four independent SNUGLITE-II captures contain shared subsequences up to 81 bytes long. Two hypotheses are compatible: (i) repeated beacon frames captured at different orbital points, and (ii) a CC1200 demodulator/idle pattern emitted repeatedly at false sync triggers. The April 9 log explicitly identifies a 99-byte CC1200 idle pattern appearing identically across all satellites at all frequencies; the SNUGLITE-II matches have not yet been shown to differ structurally from this idle pattern, so (ii) is not excluded.

\paragraph{C. Pass-profile RSSI range (weak).} A small subset of passes show an AOS-to-peak-to-LOS RSSI excursion of several dB, loosely consistent with $1/r^2$ path-loss modulation of a real signal but equally consistent with antenna noise-temperature variation as the beam sweeps across ground and sky. Not diagnostic.

\begin{figure}[H]
    \centering
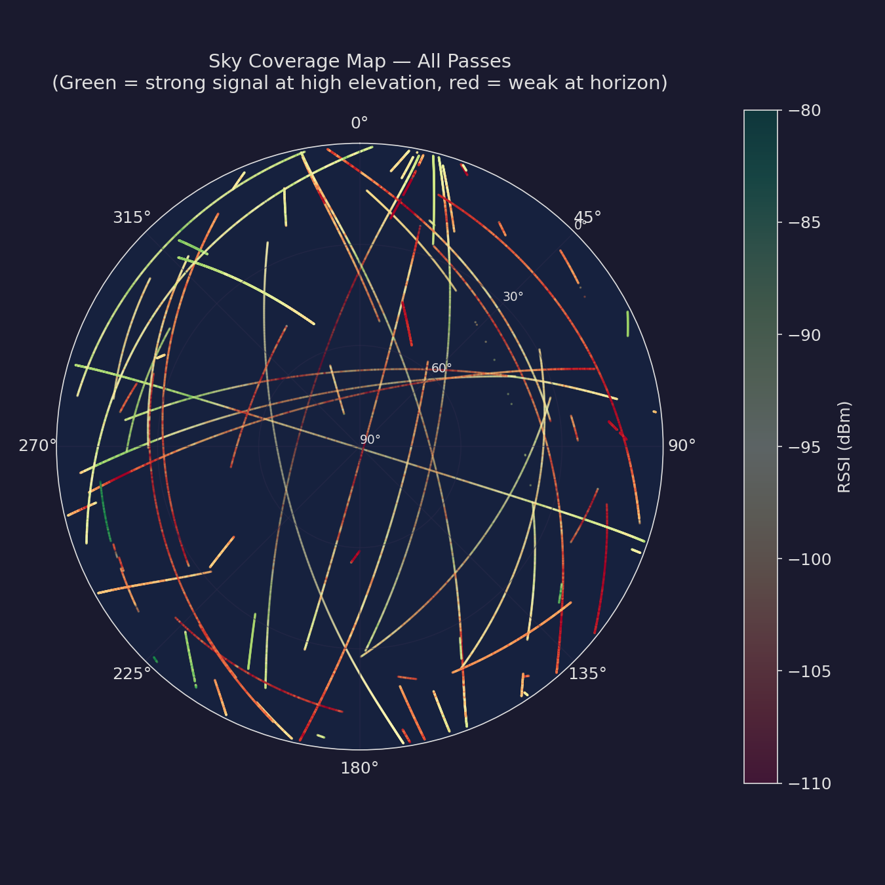
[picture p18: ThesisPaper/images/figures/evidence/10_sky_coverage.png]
    
    \caption{Sky coverage heatmap: RSSI over AZ/EL across all tracked passes.}
\end{figure}

\paragraph{D. Doppler-sweep profile (confirms orbital geometry, not reception).} The expected $\pm$9~kHz sweep at 432~MHz with zero-crossing at TCA is observed on every pass. Because this sweep is \textit{applied} by station software to the FREQOFF register regardless of whether any signal is present, it verifies correct predict/correct software behaviour only.

\begin{figure}[H]
    \centering
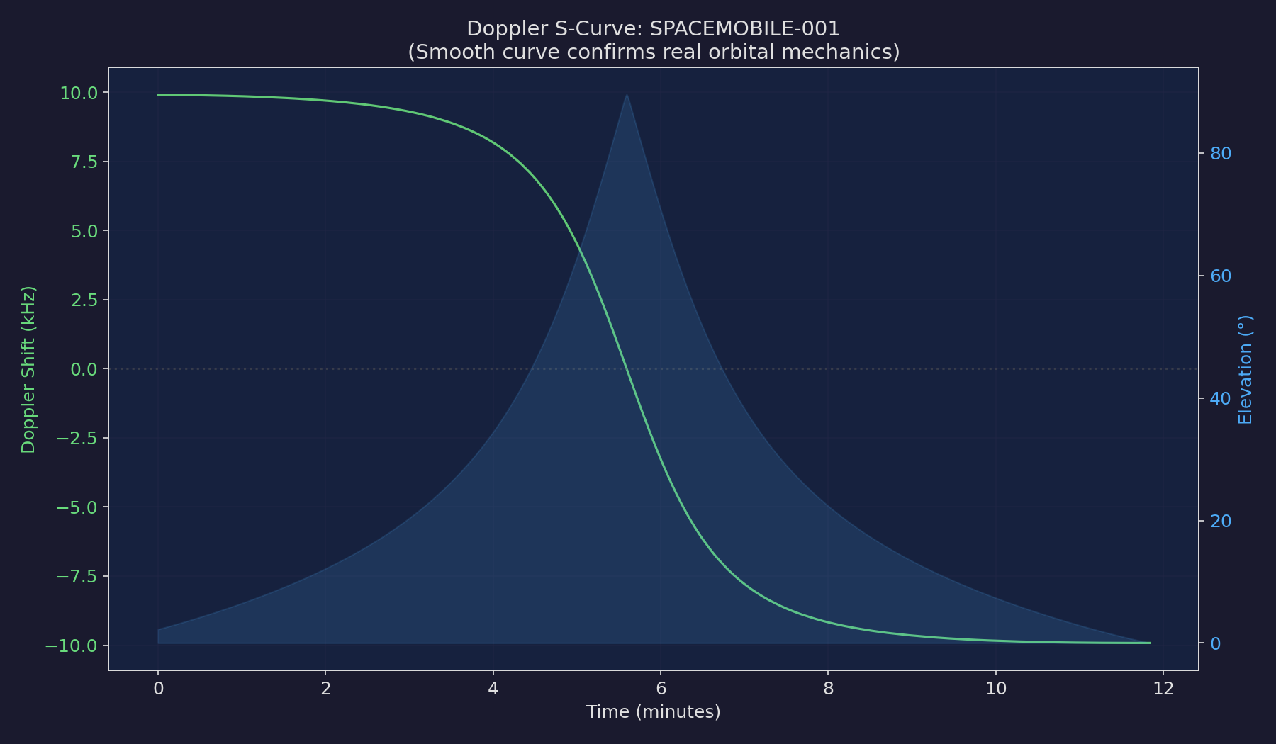
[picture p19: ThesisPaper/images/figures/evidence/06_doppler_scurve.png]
    
    \caption{Doppler-correction S-curve applied during one pass.}
\end{figure}

\paragraph{E. Capture-byte entropy (weak).} Captures show byte entropy of 6.95--7.91 bits/byte, below the 8.0 bits/byte expected of uniform random noise. Filtered or correlated noise from a demodulator can produce similar signatures without encoding any information. The entropy is consistent with ``not white noise'' but not with ``structured satellite telemetry'' specifically.

\paragraph{F. MIMAN AX.100 Mode~5 analysis (inconclusive).} MIMAN captures processed through AX.100 Mode~5 achieved Golay(24,12) decode rates of 73\,\% (April 9) and 66\,\% (April 12). The random false-positive baseline for Golay(24,12) with 3-error correction is approximately 57\,\%, so the observed rates are only marginally above chance. Zero frames passed the subsequent RS(255,223) correction. Golay matches without downstream RS-decoded content are not a definitive indicator.

\subsection{Academic Conclusion}

The primary finding is established independently of observations A--F: the theoretical margin at 30\degree\ elevation is already $-$5.7~dB at datasheet CC1200 sensitivity, and the field-measured noise floor of $-$96~dBm buries the $-$125.7~dBm received signal by approximately 30~dB, making protocol-valid decode physically impossible regardless of which secondary hypothesis explains the statistical patterns. The secondary finding is that A--F are individually consistent with both weak sub-threshold reception and receiver-internal noise artefacts, and cannot be used to distinguish between the two hypotheses. This ambiguity is expected and does not alter the root-cause diagnosis: the board-noise floor sits approximately 30~dB above the thermal\,+\,NF baseline. A mast-mounted front-end LNA is the primary intervention: its gain lifts the received signal above the fixed board-interference floor before it reaches the CC1200. However, with the field noise floor at $-$96~dBm, a 20~dB LNA still leaves the signal approximately 10~dB below the detection threshold, so the LNA must be combined with board-level EMI mitigation: improved buck-converter output filtering, a post-buck LDO on the CC1200 supply rails to suppress conducted switching noise, and a SAW bandpass filter on the antenna port to reject out-of-band interference before it reaches the LNA (\S\ref{sec:future-work}).

\subsection{AetherSpace-Specific Outlook}

For AetherSpace the modulation-match risk is lower than for arbitrary satellites because the CubeSat and the ground station use the same CC1200 transceiver, provided both sides load the same finalised SmartRF register set. The remaining risk is sensitivity, addressed in \S\ref{sec:future-work}. The software architecture already exposes an \code{RfBackend} abstraction with both CC1200 and RTL-SDR implementations, allowing an SDR-based wideband IQ capture to serve as an independent verification path once an LNA is installed.

\section{Cost Comparison}

The v2 MOTOR\_RF\_HAT BOM (from \S\ref{sec:cost}) compared against commercial and existing open-source alternatives. The ``rotator'' column counts the controller board + motors + mechanics only, excluding the station computer, antenna, coax, power supply, and tripod; ``total'' adds a Pi 3A+.

\begin{table}[H]
    \centering
    \small
    \begin{tabular}{@{}llll@{}}
        \toprule
        System & Type & Rotator (\euro{}) & +Pi (\euro{}) \\
        \midrule
        Yaesu G-5500   & Commercial    & 760--900   & 1200+ \\
        SPID RAS       & Commercial    & 1200--1300 & 1800+ \\
        SatNOGS v3     & Stepper, belt & 300--500   & 600+ \\
        \textbf{This work (v2)} & \textbf{DC + gears} & \textbf{$\sim$75} & \textbf{$\sim$100} \\
        \bottomrule
    \end{tabular}
    \caption{Cost comparison. v2 is design-complete but not yet fabricated; $\sim$\euro{}75/\euro{}100 are BOM projections (LCSC + JLCPCB, April 2026).}
\end{table}

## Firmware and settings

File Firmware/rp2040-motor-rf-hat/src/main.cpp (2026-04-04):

// MOTOR_RF_HAT Firmware — Combined motor controller + dual CC1200 RF HAT
// Single RP2040 Pico handles:
//   - 2x A4950 motor drivers (AZ + EL)
//   - 2x quadrature encoders
//   - ADXL345 IMU (SPI0, shared with VHF CC1200)
//   - UHF CC1200 (SPI1, 432 MHz)
//   - VHF CC1200 (SPI0, 144 MHz)
//   - 4x WS2812B NeoPixel
//   - Passive buzzer
// Communication: unified COBS/CRC-16 binary protocol over UART0 (GP0/GP1) to Pi 3A+

#include <Arduino.h>
#include <Adafruit_NeoPixel.h>
#include <cstdio>
#include <cmath>
#include "hardware/spi.h"
#include "hardware/uart.h"
#include "hardware/gpio.h"
#include "hardware/pwm.h"
#include "hardware/watchdog.h"
#include "pico/stdlib.h"

extern "C" {
#include "config.h"
#include "cc1200.h"
#include "proto.h"
}

#include "motor_pwm.h"
#include "quadrature.h"
#include "rotator.h"
#include "adxl345.h"

// ---------------------------------------------------------------------------
// Global instances (static lifetime, initialized in setup())
// ---------------------------------------------------------------------------
static cc1200_t radios[RADIO_COUNT];

static Adafruit_NeoPixel neopixel(NEOPIXEL_COUNT, PIN_NEOPIXEL, NEO_GRB + NEO_KHZ800);
static constexpr uint8_t LED_BR = 40;

// Motor/encoder objects — constructed in setup() as static locals
static MotorPwm*   g_az_motor = nullptr;
static MotorPwm*   g_el_motor = nullptr;
static Quadrature*  g_az_enc = nullptr;
static Quadrature*  g_el_enc = nullptr;
static Rotator*     g_rotator = nullptr;
static ADXL345*     g_imu = nullptr;
static bool         g_imu_ok = false;

// Heartbeat state
static uint32_t hb_next = 0;
static bool hb_state = false;
static bool uhf_ok_flag = false;
static bool vhf_ok_flag = false;

// PID tick timing
static absolute_time_t last_pid_tick;

// Position event streaming (10 Hz)
static uint32_t pos_evt_next = 0;

// ---------------------------------------------------------------------------
// Buzzer — non-blocking PWM tone sequencer on GP5
// ---------------------------------------------------------------------------
struct BuzzerStep { uint16_t freq_hz; uint16_t dur_ms; };

static const BuzzerStep SEQ_READY[] = {
    {1000, 100}, {0, 100}, {1000, 100}, {0, 100}, {1000, 100}, {0, 0}
};
static const BuzzerStep SEQ_AOS[] = {
    {800, 150}, {0, 50}, {1200, 150}, {0, 0}
};
static const BuzzerStep SEQ_LOS[] = {
    {1200, 150}, {0, 50}, {800, 150}, {0, 0}
};
static const BuzzerStep SEQ_PACKET[] = {
    {1500, 80}, {0, 0}
};
static const BuzzerStep SEQ_ERROR[] = {
    {400, 500}, {0, 0}
};
static const BuzzerStep SEQ_WIFI_OK[] = {
    {523, 80}, {0, 30}, {659, 80}, {0, 30}, {784, 80}, {0, 0}
};
static const BuzzerStep SEQ_GPS_OK[] = {
    {2000, 60}, {0, 40}, {2000, 60}, {0, 0}
};
static const BuzzerStep SEQ_SETUP_DONE[] = {
    {523, 80}, {0, 30}, {659, 80}, {0, 30}, {784, 80}, {0, 30},
    {1047, 80}, {0, 30}, {784, 80}, {0, 0}
};

static const BuzzerStep* bz_seq = nullptr;
static uint8_t  bz_step = 0;
static uint32_t bz_step_end = 0;
static uint      bz_slice = 0;

static void buzzer_init()
{
    gpio_set_function(PIN_BUZZER, GPIO_FUNC_PWM);
    bz_slice = pwm_gpio_to_slice_num(PIN_BUZZER);
    pwm_set_enabled(bz_slice, false);
}

static void buzzer_tone(uint16_t freq_hz)
{
    if (freq_hz == 0) {
        pwm_set_enabled(bz_slice, false);
        return;
    }
    uint32_t wrap = 125000000UL / freq_hz;
    if (wrap > 65535) wrap = 65535;
    pwm_set_wrap(bz_slice, (uint16_t)wrap);
    pwm_set_chan_level(bz_slice, pwm_gpio_to_channel(PIN_BUZZER), (uint16_t)(wrap / 2));
    pwm_set_enabled(bz_slice, true);
}

static void buzzer_start(uint8_t pattern)
{
    switch (pattern) {
        case 0x01: bz_seq = SEQ_READY;  break;
        case 0x02: bz_seq = SEQ_AOS;    break;
        case 0x03: bz_seq = SEQ_LOS;    break;
        case 0x04: bz_seq = SEQ_PACKET; break;
        case 0x05: bz_seq = SEQ_ERROR;      break;
        case 0x06: bz_seq = SEQ_WIFI_OK;    break;
        case 0x07: bz_seq = SEQ_GPS_OK;     break;
        case 0x08: bz_seq = SEQ_SETUP_DONE; break;
        default:   return;
    }
    bz_step = 0;
    buzzer_tone(bz_seq[0].freq_hz);
    bz_step_end = millis() + bz_seq[0].dur_ms;
}

static void buzzer_tick()
{
    if (!bz_seq) return;
    if (millis() < bz_step_end) return;

    bz_step++;
    if (bz_seq[bz_step].dur_ms == 0 && bz_seq[bz_step].freq_hz == 0) {
        buzzer_tone(0);
        bz_seq = nullptr;
        return;
    }
    buzzer_tone(bz_seq[bz_step].freq_hz);
    bz_step_end = millis() + bz_seq[bz_step].dur_ms;
}

static void on_buzzer_cmd(uint8_t pattern) { buzzer_start(pattern); }

// ---------------------------------------------------------------------------
// NeoPixel helpers
// ---------------------------------------------------------------------------
static void neo_set_all(uint8_t r, uint8_t g, uint8_t b)
{
    uint32_t c = neopixel.Color(r, g, b);
    for (int i = 0; i < NEOPIXEL_COUNT; i++)
        neopixel.setPixelColor(i, c);
    neopixel.show();
}

// ---------------------------------------------------------------------------
// Encoder ISR (shared GPIO callback)
// ---------------------------------------------------------------------------
static void gpio_irq_callback(uint gpio, uint32_t events) {
    (void)events;
    if (g_az_enc && (gpio == PIN_AZ_ENC_A || gpio == PIN_AZ_ENC_B)) g_az_enc->on_edge();
    if (g_el_enc && (gpio == PIN_EL_ENC_A || gpio == PIN_EL_ENC_B)) g_el_enc->on_edge();
}

static void enable_encoder_irqs() {
    const uint32_t event_mask = GPIO_IRQ_EDGE_RISE | GPIO_IRQ_EDGE_FALL;

    gpio_set_irq_enabled_with_callback(PIN_AZ_ENC_A, event_mask, true, &gpio_irq_callback);
    gpio_set_irq_enabled(PIN_AZ_ENC_B, event_mask, true);

    gpio_set_irq_enabled(PIN_EL_ENC_A, event_mask, true);
    gpio_set_irq_enabled(PIN_EL_ENC_B, event_mask, true);
}

// ---------------------------------------------------------------------------
// Radio init helper
// ---------------------------------------------------------------------------
static bool init_radio(uint8_t idx, spi_inst_t* spi, uint32_t baud,
                       uint pin_sck, uint pin_mosi, uint pin_miso, uint pin_csn,
                       uint pin_reset, const char* label)
{
    cc1200_hal_t hal = {};
    hal.spi       = spi;
    hal.baud_hz   = baud;
    hal.pin_sck   = pin_sck;
    hal.pin_mosi  = pin_mosi;
    hal.pin_miso  = pin_miso;
    hal.pin_csn   = pin_csn;
    hal.pin_reset = pin_reset;
    hal.so_ready_timeout_us = CC1200_SO_READY_TIMEOUT_US;

    if (!cc1200_init(&radios[idx], &hal)) {
        Serial.printf("[%s] HAL init failed\n", label);
        return false;
    }

    if (!cc1200_begin(&radios[idx])) {
        Serial.printf("[%s] CC1200 reset/begin failed\n", label);
        return false;
    }

    uint8_t part = 0, ver = 0;
    cc1200_read_ext(&radios[idx], 0x8F, &part);
    cc1200_read_ext(&radios[idx], 0x90, &ver);

    Serial.printf("[%s] CC1200 part=0x%02X ver=0x%02X %s\n",
                  label, part, ver, (part == 0x20) ? "OK" : "FAIL");

    return (part == 0x20);
}

// ---------------------------------------------------------------------------
// Motor protocol callbacks
// ---------------------------------------------------------------------------
static void cb_motor_set_position(float az_deg, float el_deg) {
    if (g_rotator) g_rotator->set_target(az_deg, el_deg);
}

static void cb_motor_get_position(float* az_deg, float* el_deg, uint8_t* status) {
    if (g_rotator) {
        auto st = g_rotator->status();
        *az_deg = st.az_deg;
        *el_deg = st.el_deg;
        *status = st.moving ? 2u : 1u;
    }
}

static void cb_motor_park(void) {
    if (g_rotator) g_rotator->park();
}

static void cb_motor_stop(void) {
    if (g_rotator) g_rotator->stop_all();
}

static void cb_motor_home(void);  // forward decl — needs IMU access

static void cb_motor_get_status(uint8_t* buf, uint16_t* len) {
    if (!g_rotator) { *len = 0; return; }
    auto st = g_rotator->status();
    // state_u8, fault_u8, homed_u8, az_f32, el_f32, az_tgt_f32, el_tgt_f32
    buf[0] = st.moving ? 2u : 1u;
    buf[1] = (st.error_reg & 8u) ? 1u : 0u;
    buf[2] = (st.az_homed && st.el_homed) ? 1u : 0u;

    // Float LE helper (same as proto.c put_f32_le)
    union { float f; uint8_t b[4]; } u;
    u.f = st.az_deg;   memcpy(&buf[3], u.b, 4);
    u.f = st.el_deg;   memcpy(&buf[7], u.b, 4);
    // Target positions — get from status (current = target when on-target)
    // We need actual targets, so access rotator internals via status
    u.f = st.az_deg;   memcpy(&buf[11], u.b, 4); // approximate (status doesn't expose target)
    u.f = st.el_deg;   memcpy(&buf[15], u.b, 4);
    *len = 19;
}

static void cb_motor_set_gains(float kp, float ki, float kd) {
    if (g_rotator) g_rotator->set_gains(kp, ki, kd);
}

static void cb_motor_zero_encoders(void) {
    if (g_rotator) g_rotator->zero_encoders();
}

static void cb_imu_read(uint8_t* buf, uint16_t* len) {
    if (!g_imu || !g_imu_ok) { *len = 0; return; }

    // Switch SPI0 to mode 3 for ADXL345
    spi_deinit(spi0);
    spi_init(spi0, 1000000);
    spi_set_format(spi0, 8, SPI_CPOL_1, SPI_CPHA_1, SPI_MSB_FIRST);
    gpio_set_function(VHF_PIN_SCK, GPIO_FUNC_SPI);
    gpio_set_function(VHF_PIN_MOSI, GPIO_FUNC_SPI);
    gpio_set_function(VHF_PIN_MISO, GPIO_FUNC_SPI);

    float x, y, z;
    g_imu->read_accel(&x, &y, &z);
    float el = g_imu->elevation_deg();

    // Switch back to mode 0 for VHF CC1200
    spi_deinit(spi0);
    spi_init(spi0, 5000000);
    spi_set_format(spi0, 8, SPI_CPOL_0, SPI_CPHA_0, SPI_MSB_FIRST);
    gpio_set_function(VHF_PIN_SCK, GPIO_FUNC_SPI);
    gpio_set_function(VHF_PIN_MOSI, GPIO_FUNC_SPI);
    gpio_set_function(VHF_PIN_MISO, GPIO_FUNC_SPI);

    union { float f; uint8_t b[4]; } u;
    u.f = x;   memcpy(&buf[0], u.b, 4);
    u.f = y;   memcpy(&buf[4], u.b, 4);
    u.f = z;   memcpy(&buf[8], u.b, 4);
    u.f = el;  memcpy(&buf[12], u.b, 4);
    *len = 16;
}

static void cb_motor_recal(void) {
    if (!g_imu || !g_imu_ok || !g_rotator) return;

    // Switch SPI0 to mode 3 for ADXL345
    spi_deinit(spi0);
    spi_init(spi0, 1000000);
    spi_set_format(spi0, 8, SPI_CPOL_1, SPI_CPHA_1, SPI_MSB_FIRST);
    gpio_set_function(VHF_PIN_SCK, GPIO_FUNC_SPI);
    gpio_set_function(VHF_PIN_MOSI, GPIO_FUNC_SPI);
    gpio_set_function(VHF_PIN_MISO, GPIO_FUNC_SPI);

    float el = g_imu->elevation_deg_averaged(20);
    g_rotator->calibrate_el(el);
    Serial.printf("RECAL: IMU reads %.1f deg, encoder re-zeroed\n", el);

    // Switch back to mode 0 for VHF CC1200
    spi_deinit(spi0);
    spi_init(spi0, 5000000);
    spi_set_format(spi0, 8, SPI_CPOL_0, SPI_CPHA_0, SPI_MSB_FIRST);
    gpio_set_function(VHF_PIN_SCK, GPIO_FUNC_SPI);
    gpio_set_function(VHF_PIN_MOSI, GPIO_FUNC_SPI);
    gpio_set_function(VHF_PIN_MISO, GPIO_FUNC_SPI);
}

// IMU re-homing: drive EL motor to horizontal using IMU feedback
// This is blocking (~15s max) — same as original rotator homing
static void cb_motor_home(void) {
    if (!g_imu || !g_imu_ok || !g_rotator || !g_el_motor) return;

    // Switch SPI0 to mode 3 for ADXL345
    spi_deinit(spi0);
    spi_init(spi0, 1000000);
    spi_set_format(spi0, 8, SPI_CPOL_1, SPI_CPHA_1, SPI_MSB_FIRST);
    gpio_set_function(VHF_PIN_SCK, GPIO_FUNC_SPI);
    gpio_set_function(VHF_PIN_MOSI, GPIO_FUNC_SPI);
    gpio_set_function(VHF_PIN_MISO, GPIO_FUNC_SPI);

    constexpr float kElHomingDeadband = 1.5f;
    constexpr float kElHomingDuty = 0.25f;
    constexpr uint32_t kElHomingTimeout = 15000;
    const uint32_t start = to_ms_since_boot(get_absolute_time());

    while (to_ms_since_boot(get_absolute_time()) - start < kElHomingTimeout) {
        float el = g_imu->elevation_deg_averaged(3);
        if (std::abs(el) <= kElHomingDeadband) {
            g_el_motor->stop();
            g_rotator->calibrate_el(0.0f);
            break;
        }
        float duty = (el > 0) ? -kElHomingDuty : kElHomingDuty;
        g_el_motor->set(duty);
        watchdog_update();
        sleep_ms(50);
    }
    g_el_motor->stop();

    // Fallback: calibrate from current IMU reading
    float fallback = g_imu->elevation_deg_averaged(10);
    g_rotator->calibrate_el(fallback);

    g_rotator->calibrate_az_zero();

    // Switch back to mode 0 for VHF CC1200
    spi_deinit(spi0);
    spi_init(spi0, 5000000);
    spi_set_format(spi0, 8, SPI_CPOL_0, SPI_CPHA_0, SPI_MSB_FIRST);
    gpio_set_function(VHF_PIN_SCK, GPIO_FUNC_SPI);
    gpio_set_function(VHF_PIN_MOSI, GPIO_FUNC_SPI);
    gpio_set_function(VHF_PIN_MISO, GPIO_FUNC_SPI);
}

// ---------------------------------------------------------------------------
// Arduino entry points
// ---------------------------------------------------------------------------
void setup()
{
    // USB serial for debug output
    Serial.begin(115200);

    // Onboard LED
    pinMode(PIN_LED, OUTPUT);
    digitalWrite(PIN_LED, HIGH);

    // Wait for USB serial (up to 3s)
    uint32_t usb_wait_start = millis();
    while (!Serial && (millis() - usb_wait_start < 3000)) {
        delay(10);
    }

    Serial.println("\n=== MOTOR_RF_HAT Firmware ===");
    Serial.printf("Pins: NEOPIXEL=%d BUZZER=%d UART_TX=%d UART_RX=%d\n",
                  PIN_NEOPIXEL, PIN_BUZZER, PIN_UART_TX, PIN_UART_RX);
    Serial.printf("AZ: IN1=%d IN2=%d ENC_A=%d ENC_B=%d\n",
                  PIN_AZ_IN1, PIN_AZ_IN2, PIN_AZ_ENC_A, PIN_AZ_ENC_B);
    Serial.printf("EL: IN1=%d IN2=%d ENC_A=%d ENC_B=%d\n",
                  PIN_EL_IN1, PIN_EL_IN2, PIN_EL_ENC_A, PIN_EL_ENC_B);
    Serial.flush();

    // 1. NeoPixel init
    neopixel.begin();
    neo_set_all(LED_BR, LED_BR, LED_BR);  // white = booting

    // 2. Buzzer init + boot chime
    buzzer_init();
    static const uint16_t chime[] = {523, 659, 784, 1047};
    for (int i = 0; i < 4; i++) {
        buzzer_tone(chime[i]);
        delay(80);
    }
    buzzer_tone(0);

    // 3. Initialize UART0 for Pi communication
    uart_init(uart0, UART_BAUD);
    gpio_set_function(PIN_UART_TX, GPIO_FUNC_UART);
    gpio_set_function(PIN_UART_RX, GPIO_FUNC_UART);
    uart_set_format(uart0, 8, 1, UART_PARITY_NONE);
    uart_set_fifo_enabled(uart0, true);
    Serial.printf("UART0: %d baud\n", UART_BAUD);
    Serial.flush();

    // 4. Init UHF CC1200 on SPI1
    Serial.println("Init UHF CC1200 on SPI1...");
    Serial.flush();
    uhf_ok_flag = init_radio(RADIO_UHF, UHF_SPI_INST, UHF_SPI_BAUD_HZ,
                              UHF_PIN_SCK, UHF_PIN_MOSI, UHF_PIN_MISO, UHF_PIN_CSN,
                              UHF_PIN_RESET, "UHF");

    // 5. ADXL345 IMU init on SPI0 mode 3
    // SPI0 starts unconfigured — ADXL345::init() sets it up in mode 3
    Serial.println("Init ADXL345 IMU on SPI0 (mode 3)...");
    Serial.flush();
    static ADXL345 imu(PIN_IMU_CS, VHF_PIN_SCK, VHF_PIN_MOSI, VHF_PIN_MISO);
    g_imu = &imu;
    g_imu_ok = imu.init();
    Serial.printf("IMU: %s (ID=0x%02X)\n", g_imu_ok ? "OK" : "NOT FOUND", imu.device_id());
    Serial.flush();

    // 6. Motor PWM init (A4950 2-pin mode)
    static MotorPwm az_motor(PIN_AZ_IN1, PIN_AZ_IN2);
    static MotorPwm el_motor(PIN_EL_IN1, PIN_EL_IN2);
    az_motor.init(motor_config::kPwmHz);
    el_motor.init(motor_config::kPwmHz);
    g_az_motor = &az_motor;
    g_el_motor = &el_motor;

    // 7. Encoder init
    static Quadrature az_enc(PIN_AZ_ENC_A, PIN_AZ_ENC_B);
    static Quadrature el_enc(PIN_EL_ENC_A, PIN_EL_ENC_B);
    az_enc.init();
    el_enc.init();
    g_az_enc = &az_enc;
    g_el_enc = &el_enc;
    enable_encoder_irqs();

    // 8. Rotator init
    static Rotator rotator(az_motor, el_motor, az_enc, el_enc);
    rotator.init();
    g_rotator = &rotator;

    // 9. AZ calibration: assume north at boot
    rotator.calibrate_az_zero();

    // 10. EL homing via IMU (blocking, up to 15s)
    // SPI0 is still in mode 3 from ADXL345 init
    if (g_imu_ok) {
        const float initial_el = imu.elevation_deg_averaged(10);
        Serial.printf("EL homing: IMU reads %.1f deg, driving to horizontal...\n", initial_el);
        Serial.flush();
        neo_set_all(0, 0, LED_BR);  // blue = homing

        constexpr float kElHomingDeadband = 1.5f;
        constexpr float kElHomingDuty = 0.25f;
        constexpr uint32_t kElHomingTimeout = 15000;
        const uint32_t homing_start = to_ms_since_boot(get_absolute_time());
        bool homed = false;

        while (to_ms_since_boot(get_absolute_time()) - homing_start < kElHomingTimeout) {
            const float el = imu.elevation_deg_averaged(3);

            if (std::abs(el) <= kElHomingDeadband) {
                el_motor.stop();
                rotator.calibrate_el(0.0f);
                Serial.printf("EL homed to horizontal (IMU: %.1f deg)\n", el);
                homed = true;
                break;
            }

            const float duty = (el > 0) ? -kElHomingDuty : kElHomingDuty;
            el_motor.set(duty);
            watchdog_update();
            sleep_ms(50);
        }

        if (!homed) {
            el_motor.stop();
            const float fallback = imu.elevation_deg_averaged(20);
            rotator.calibrate_el(fallback);
            Serial.printf("EL homing timeout -- calibrated from IMU at %.1f deg\n", fallback);
        }
    } else {
        rotator.calibrate_el(0.0f);
        Serial.println("IMU not found -- EL assumed 0 (place antenna horizontal)");
    }

    // 11. Switch SPI0 to mode 0 for VHF CC1200
    spi_deinit(spi0);
    spi_init(spi0, VHF_SPI_BAUD_HZ);
    spi_set_format(spi0, 8, SPI_CPOL_0, SPI_CPHA_0, SPI_MSB_FIRST);
    gpio_set_function(VHF_PIN_SCK, GPIO_FUNC_SPI);
    gpio_set_function(VHF_PIN_MOSI, GPIO_FUNC_SPI);
    gpio_set_function(VHF_PIN_MISO, GPIO_FUNC_SPI);

    // 12. Init VHF CC1200 on SPI0
    Serial.println("Init VHF CC1200 on SPI0...");
    Serial.flush();
    vhf_ok_flag = init_radio(RADIO_VHF, VHF_SPI_INST, VHF_SPI_BAUD_HZ,
                              VHF_PIN_SCK, VHF_PIN_MOSI, VHF_PIN_MISO, VHF_PIN_CSN,
                              VHF_PIN_RESET, "VHF");

    Serial.printf("UHF: %s  VHF: %s\n", uhf_ok_flag ? "OK" : "FAIL", vhf_ok_flag ? "OK" : "FAIL");
    Serial.flush();

    // 13. Init protocol handler with radios + callbacks
    proto_init(radios, RADIO_COUNT);
    proto_set_buzzer_cb(on_buzzer_cmd);

    // Motor callbacks
    proto_set_motor_set_position_cb(cb_motor_set_position);
    proto_set_motor_get_position_cb(cb_motor_get_position);
    proto_set_motor_park_cb(cb_motor_park);
    proto_set_motor_stop_cb(cb_motor_stop);
    proto_set_motor_home_cb(cb_motor_home);
    proto_set_motor_get_status_cb(cb_motor_get_status);
    proto_set_motor_set_gains_cb(cb_motor_set_gains);
    proto_set_motor_zero_encoders_cb(cb_motor_zero_encoders);
    proto_set_imu_read_cb(cb_imu_read);
    proto_set_motor_recal_cb(cb_motor_recal);

    // Register USB Serial as protocol channel 1 (for bench testing)
    proto_set_write_fn(1, [](const uint8_t* data, size_t len) {
        Serial.write(data, len);
        Serial.flush();
    });

    // Enable position event streaming by default
    proto_set_position_streaming(true);

    // Status LED
    if (uhf_ok_flag) {
        neo_set_all(0, LED_BR, 0);  // green = ready
        buzzer_start(0x01);
        Serial.println("STATUS: UHF OK -- NeoPixel GREEN, buzzer READY");
    } else {
        neo_set_all(LED_BR, 0, 0);  // red = UHF init fault
        buzzer_start(0x05);
        Serial.println("STATUS: UHF FAIL -- NeoPixel RED, buzzer ERROR");
    }
    Serial.flush();

    Serial.println("Ready -- UART0 + USB protocol active, motors + RF online");
    Serial.flush();

    hb_next = millis() + 500;
    last_pid_tick = get_absolute_time();
    pos_evt_next = millis() + 100;

    // Hardware watchdog — 8 second timeout
    watchdog_enable(8000, true);
}

void loop()
{
    // 100 Hz motor PID tick
    if (absolute_time_diff_us(last_pid_tick, get_absolute_time()) >= 10000) {
        if (g_rotator) g_rotator->tick();
        last_pid_tick = get_absolute_time();
    }

    // Heartbeat LED + NeoPixel update (~1 Hz)
    if (millis() >= hb_next) {
        hb_state = !hb_state;
        digitalWrite(PIN_LED, hb_state ? HIGH : LOW);
        hb_next = millis() + 500;

        // Update NeoPixel based on state
        if (!uhf_ok_flag) {
            neo_set_all(LED_BR, 0, 0);      // red = UHF fault
        } else if (proto_is_streaming()) {
            neo_set_all(0, 0, LED_BR);       // blue = RX streaming
        } else if (g_rotator && g_rotator->status().moving) {
            neo_set_all(0, LED_BR, LED_BR);  // cyan = motor tracking
        } else {
            neo_set_all(0, LED_BR, 0);       // green = idle/ready
        }
    }

    watchdog_update();

    // Buzzer tone sequencer
    buzzer_tick();

    // Protocol poll (UART + RX streaming)
    proto_poll();

    // Feed USB Serial bytes into protocol handler (channel 1)
    int avail = Serial.available();
    if (avail > 0) {
        uint8_t usb_buf[64];
        int n = Serial.readBytes(usb_buf, (avail > 64) ? 64 : avail);
        if (n > 0)
            proto_feed_bytes(usb_buf, (size_t)n, 1);
    }

    // 10 Hz position event stream
    if (proto_is_position_streaming() && millis() >= pos_evt_next) {
        if (g_rotator) {
            auto st = g_rotator->status();
            proto_send_position_event(st.az_deg, st.el_deg, st.moving ? 2u : 1u);
        }
        pos_evt_next = millis() + 100;
    }

    // Small yield
    delay(1);
}

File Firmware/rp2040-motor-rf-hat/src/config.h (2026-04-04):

#pragma once
#include <stdint.h>

// =============================================================================
// MOTOR_RF_HAT Pin Configuration — Combined motor controller + RF HAT
// =============================================================================
//
// Architecture:
//   Pi 3A+ (UART) --> Pico --> SPI1 --> CC1200 UHF (432 MHz)
//                          --> SPI0 --> CC1200 VHF (144 MHz) + ADXL345 IMU
//                          --> A4950 x2 (AZ + EL motor drivers)
//                          --> Quadrature encoders x2

// ---- UART to Raspberry Pi (UART0) ----
#define PIN_UART_TX          0   // GP0 -> Pi GPIO15 (RXD)
#define PIN_UART_RX          1   // GP1 -> Pi GPIO14 (TXD)
#define UART_BAUD           115200

// ---- AZ Motor (A4950, 2-pin PWM mode) ----
#define PIN_AZ_IN1           2   // GP2 — PWM for forward
#define PIN_AZ_IN2           3   // GP3 — PWM for reverse

// ---- WS2812B NeoPixel status LEDs ----
#define PIN_NEOPIXEL         4   // GP4 — WS2812B data-in (chain of 4)
#define NEOPIXEL_COUNT       4

// ---- Passive buzzer (on Pico, via switching transistor) ----
#define PIN_BUZZER           5   // GP5 — PWM to NPN/MOSFET gate driving buzzer

// ---- UHF CC1200 (432 MHz) on SPI1 ----
#define UHF_SPI_INST        spi1
#define UHF_SPI_BAUD_HZ     (5 * 1000 * 1000)
#define UHF_PIN_GPIO0         7  // GP7 — UHF CC1200 GPIO0 (packet sync)
#define UHF_PIN_RESET         8  // GP8
#define UHF_PIN_SCK          10  // GP10
#define UHF_PIN_MOSI         11  // GP11
#define UHF_PIN_MISO         12  // GP12
#define UHF_PIN_CSN          13  // GP13

// ---- AZ Quadrature Encoder ----
#define PIN_AZ_ENC_A         14  // GP14
#define PIN_AZ_ENC_B         15  // GP15

// ---- VHF CC1200 (144 MHz) on SPI0 (shared with IMU) ----
#define VHF_SPI_INST        spi0
#define VHF_SPI_BAUD_HZ     (5 * 1000 * 1000)
#define VHF_PIN_MISO         16  // GP16 (shared with IMU)
#define VHF_PIN_CSN          17  // GP17
#define VHF_PIN_SCK          18  // GP18 (shared with IMU)
#define VHF_PIN_MOSI         19  // GP19 (shared with IMU)
#define VHF_PIN_RESET        20  // GP20

// ---- EL Quadrature Encoder ----
#define PIN_EL_ENC_A         21  // GP21
#define PIN_EL_ENC_B         22  // GP22

// ---- ADXL345 IMU on SPI0 (shared bus with VHF CC1200, mode switching) ----
#define PIN_IMU_CS           26  // GP26
// IMU uses VHF_PIN_SCK (GP18), VHF_PIN_MOSI (GP19), VHF_PIN_MISO (GP16)

// ---- EL Motor (A4950, 2-pin PWM mode) ----
#define PIN_EL_IN1           27  // GP27 — PWM for forward
#define PIN_EL_IN2           28  // GP28 — PWM for reverse

// ---- Common ----
#define CC1200_SO_READY_TIMEOUT_US  5000

// ---- Onboard LED (Pico) ----
// PIN_LED already defined by Arduino-Pico variant (pin 25)

// ---- Radio selection ----
#define RADIO_UHF   0
#define RADIO_VHF   1
#define RADIO_COUNT 2

// =============================================================================
// Motor/Rotator Configuration — from rp2040-satnogs-rotator config.h
// =============================================================================
// Motor: FAPG36-555-EN, 24V, 6mm shaft, 16 RPM
// Internal gearbox: 516:1 | External: AZ 40/15, EL 55/40

#ifdef __cplusplus
namespace motor_config {

// Homing via endstop switches (repeatable absolute reference at startup).
constexpr bool kUseEndstopHoming = false; // Set true once endstops are wired

// ALERT pins — A4950 has no ALERT output, so always ignore.
constexpr bool kIgnoreDriverFaults = true;

// Encoder ticks per degree of axis output rotation.
constexpr float kAzTicksPerDegree = 244.6f; // 64 ticks/rev x 516:1 gearbox x 40/15 external
constexpr float kElTicksPerDegree = 126.1f; // 64 ticks/rev x 516:1 gearbox x 55/40 external

// Direction conventions: if an axis moves the wrong way, flip the sign.
constexpr bool kAzInvert = false;
constexpr bool kElInvert = true;

// Endstop polarity: true means GPIO reads 0 when switch is pressed.
constexpr bool kEndstopActiveLow = true;

// Soft limits (degrees).
// AZ: no slip ring, +/-360 from north (720 total). Rewind (PARK) between passes.
constexpr float kAzMinDeg = -360.0f;
constexpr float kAzMaxDeg = 360.0f;
constexpr float kElMinDeg = 0.0f;
constexpr float kElMaxDeg = 180.0f;

// Park position (degrees).
constexpr float kParkAzDeg = 0.0f;
constexpr float kParkElDeg = 0.0f;

// PID control loop
constexpr float kDeadbandDeg = 0.05f;    // tight deadband for smooth continuous tracking
constexpr float kKp = 0.15f;
constexpr float kKi = 0.03f;
constexpr float kKd = 0.02f;
constexpr float kIntegralMaxDeg = 5.0f;  // anti-windup clamp (degrees*seconds)
constexpr float kDtSeconds = 0.01f;      // 100 Hz tick rate
constexpr float kDFilterAlpha = 0.15f;   // D-term low-pass filter (0..1, lower = more filtering)
constexpr float kDutyFilterAlpha = 0.15f; // duty output smoothing (0..1, lower = smoother)
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

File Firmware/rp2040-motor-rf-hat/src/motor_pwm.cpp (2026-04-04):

#include "motor_pwm.h"

#include <algorithm>

#include "hardware/gpio.h"
#include "hardware/clocks.h"
#include "hardware/pwm.h"
#include "pico/stdlib.h"

MotorPwm::MotorPwm(uint in1_gpio, uint in2_gpio)
    : in1_gpio_(in1_gpio),
      in2_gpio_(in2_gpio),
      in1_slice_(0),
      in1_channel_(0),
      in2_slice_(0),
      in2_channel_(0),
      pwm_wrap_(0) {}

void MotorPwm::init(uint32_t pwm_hz) {
  // Both IN1 and IN2 are PWM outputs for A4950 2-pin mode.
  gpio_set_function(in1_gpio_, GPIO_FUNC_PWM);
  in1_slice_ = pwm_gpio_to_slice_num(in1_gpio_);
  in1_channel_ = pwm_gpio_to_channel(in1_gpio_);

  gpio_set_function(in2_gpio_, GPIO_FUNC_PWM);
  in2_slice_ = pwm_gpio_to_slice_num(in2_gpio_);
  in2_channel_ = pwm_gpio_to_channel(in2_gpio_);

  // Compute wrap for desired PWM frequency.
  // f_pwm = f_sys / (clkdiv * (wrap + 1))
  const uint32_t sys_hz = clock_get_hz(clk_sys);
  float clkdiv = 1.0f;
  uint32_t wrap = (sys_hz / pwm_hz) - 1u;
  if (wrap > 0xFFFF) {
    clkdiv = static_cast<float>(wrap + 1u) / 65536.0f;
    wrap = static_cast<uint32_t>((sys_hz / (pwm_hz * clkdiv)) - 1u);
    wrap = std::min<uint32_t>(wrap, 0xFFFF);
  }
  pwm_wrap_ = static_cast<uint16_t>(wrap);

  // Configure IN1 PWM slice
  pwm_set_clkdiv(in1_slice_, clkdiv);
  pwm_set_wrap(in1_slice_, pwm_wrap_);
  pwm_set_chan_level(in1_slice_, in1_channel_, 0);
  pwm_set_enabled(in1_slice_, true);

  // Configure IN2 PWM slice (may be same slice if pins are on same slice)
  if (in2_slice_ != in1_slice_) {
    pwm_set_clkdiv(in2_slice_, clkdiv);
    pwm_set_wrap(in2_slice_, pwm_wrap_);
  }
  pwm_set_chan_level(in2_slice_, in2_channel_, 0);
  if (in2_slice_ != in1_slice_) {
    pwm_set_enabled(in2_slice_, true);
  }
}

void MotorPwm::set(float duty) {
  duty = std::clamp(duty, -1.0f, 1.0f);
  if (duty == 0.0f) {
    stop();
    return;
  }

  const float abs_duty = std::abs(duty);
  const uint16_t level = static_cast<uint16_t>(abs_duty * static_cast<float>(pwm_wrap_));

  if (duty > 0.0f) {
    // Forward: IN1=duty, IN2=0
    pwm_set_chan_level(in1_slice_, in1_channel_, level);
    pwm_set_chan_level(in2_slice_, in2_channel_, 0);
  } else {
    // Reverse: IN1=0, IN2=duty
    pwm_set_chan_level(in1_slice_, in1_channel_, 0);
    pwm_set_chan_level(in2_slice_, in2_channel_, level);
  }
}

void MotorPwm::stop() {
  // Coast: both outputs low
  pwm_set_chan_level(in1_slice_, in1_channel_, 0);
  pwm_set_chan_level(in2_slice_, in2_channel_, 0);
}

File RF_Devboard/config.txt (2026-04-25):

// Rf settings for CC1200
RF_SETTINGS code rfSettings = {
    0x06,  // IOCFG3                GPIO3 IO Pin Configuration
    0x06,  // IOCFG2                GPIO2 IO Pin Configuration
    0x30,  // IOCFG1                GPIO1 IO Pin Configuration
    0x3C,  // IOCFG0                GPIO0 IO Pin Configuration
    0x55,  // SYNC3                 Sync Word Configuration [31:24]
    0x55,  // SYNC2                 Sync Word Configuration [23:16]
    0x7A,  // SYNC1                 Sync Word Configuration [15:8]
    0x0E,  // SYNC0                 Sync Word Configuration [7:0]
    0x48,  // SYNC_CFG1             Sync Word Detection Configuration Reg. 1
    0x23,  // SYNC_CFG0             Sync Word Detection Configuration Reg. 0
    0x06,  // DEVIATION_M           Frequency Deviation Configuration
    0x09,  // MODCFG_DEV_E          Modulation Format and Frequency Deviation Configur..
    0x56,  // DCFILT_CFG            Digital DC Removal Configuration
    0x14,  // PREAMBLE_CFG1         Preamble Length Configuration Reg. 1
    0xBA,  // PREAMBLE_CFG0         Preamble Detection Configuration Reg. 0
    0xC8,  // IQIC                  Digital Image Channel Compensation Configuration
    0x8E,  // CHAN_BW               Channel Filter Configuration
    0x40,  // MDMCFG1               General Modem Parameter Configuration Reg. 1
    0x05,  // MDMCFG0               General Modem Parameter Configuration Reg. 0
    0x4F,  // SYMBOL_RATE2          Symbol Rate Configuration Exponent and Mantissa [1..
    0x75,  // SYMBOL_RATE1          Symbol Rate Configuration Mantissa [15:8]
    0x10,  // SYMBOL_RATE0          Symbol Rate Configuration Mantissa [7:0]
    0x33,  // AGC_REF               AGC Reference Level Configuration
    0xF1,  // AGC_CS_THR            Carrier Sense Threshold Configuration
    0x00,  // AGC_GAIN_ADJUST       RSSI Offset Configuration
    0xB1,  // AGC_CFG3              Automatic Gain Control Configuration Reg. 3
    0x20,  // AGC_CFG2              Automatic Gain Control Configuration Reg. 2
    0x11,  // AGC_CFG1              Automatic Gain Control Configuration Reg. 1
    0x90,  // AGC_CFG0              Automatic Gain Control Configuration Reg. 0
    0x80,  // FIFO_CFG              FIFO Configuration
    0x00,  // DEV_ADDR              Device Address Configuration
    0x0B,  // SETTLING_CFG          Frequency Synthesizer Calibration and Settling Con..
    0x14,  // FS_CFG                Frequency Synthesizer Configuration
    0x08,  // WOR_CFG1              eWOR Configuration Reg. 1
    0x21,  // WOR_CFG0              eWOR Configuration Reg. 0
    0x00,  // WOR_EVENT0_MSB        Event 0 Configuration MSB
    0x00,  // WOR_EVENT0_LSB        Event 0 Configuration LSB
    0x00,  // RXDCM_TIME            RX Duty Cycle Mode Configuration
    0x00,  // PKT_CFG2              Packet Configuration Reg. 2
    0x07,  // PKT_CFG1              Packet Configuration Reg. 1
    0x20,  // PKT_CFG0              Packet Configuration Reg. 0
    0x0F,  // RFEND_CFG1            RFEND Configuration Reg. 1
    0x00,  // RFEND_CFG0            RFEND Configuration Reg. 0
    0x7F,  // PA_CFG1               Power Amplifier Configuration Reg. 1
    0x56,  // PA_CFG0               Power Amplifier Configuration Reg. 0
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

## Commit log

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2026-03-03 update RF_HAT to have WS2812 and buzzer. Start on webserver interface with demo visuals, integration in satnogs system, dual SPI and UART to USB on the Pi_HAT, update readme's
    [Pico_SPI_Host.kicad_sch, RF_HAT.kicad_pcb, RF_HAT.kicad_sch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]
2026-03-04 fix farnell BOM, final HAT design with UX elements. Added thesispaper directory. made latex environment and wrote first 2 chapters
    [RF_HATV1_bom.csv, RF_HATV1_designators.csv, RF_HATV1_positions.csv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]
2026-03-18 Add RTL-SDR backend, WiFi provisioning, dashboard multi-page redesign
    RF backend abstraction:
    - RfBackend ABC in rf_backend.py, RfHatManager now implements it
    - RtlSdrBackend: IQ capture, signal power (dBFS), post-pass waterfall
    - waterfall.py: chunked spectrogram generator for Pi 3A+ (50MB RAM cap)
    - station.py --rf-mode {auto,cc1200,rtlsdr,none} replaces --no-rf
    - Dashboard RF source dropdown writes rf_mode to station.conf
    Pi deployment:
    - setup-pi.sh: single script for fresh Bookworm install (WiFi, UART,
    rotctld, services, SSH)
    - fix-wifi.sh: nuclear rfkill fix for Trixie (masks systemd-rfkill)
    - wifi_provision.py: AP captive portal for field WiFi provisioning
    - wifi-provision.service: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
    [dashboard.py, rf_backend.py, station.py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]
2026-03-18 Fix critical bugs, polish dashboard UX, fix satellite hopping
    Bug fixes:
    - Control page AZ/EL display used undefined vars (az/el → _currentAz/_currentEl)
    - Phone compass calibration sent az:0 instead of _phoneHeading
    - Pass banner countdown showed raw seconds, now uses fmtDuration()
    - Replace all alert() calls with inline feedback
    - Connection lost state now updates station state bar
    - Shutdown screen color: red → green (safe to disconnect, not error)
    UX polish:
    - Station state bar: always visible, shows tracking/waiting/parked/disconnected/LOS
    - Pass list dims during tracking, highlights active satellite
    - LOS detection: "Pass Complete" flash + immediate pass list refresh
    - Satellite n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
    [station.py]
2026-03-18 Fix pass API performance (31s → 0.14s), background computation cache
    The /api/passes endpoint was computing orbital predictions for 220+
    satellites synchronously on every HTTP request, taking 31 seconds on
    Pi 3A+. Now computed in the background polling thread every 2 minutes,
    cached result returned instantly.
    [dashboard.py]
2026-03-18 Add stop tracking, sky plot satellite/antenna indicators, pass skip fix
    Stop tracking:
    - POST /api/stop writes ~/.station_stop flag
    - station.py checks for stop file in tracking loop, breaks on detection
    - Stop button in pass banner and station state bar during tracking
    Sky plot improvements:
    - Green diamond marker shows satellite's interpolated position on trajectory
    - Cyan dot shows antenna pointing direction
    - Labels: "SAT" (green) and "ANT" (cyan) next to each marker
    - Completed trajectory portion drawn in green
    - Satellite name labels at AOS for active/selected/next passes
    Station fixes:
    - Skip passes >20% elapsed (prevents mid-pass hopping)
    - LOS detection triggers immediate pass lis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
    [dashboard.py, station.py]
2026-03-18 Add auto-track toggle, stop+park, track feedback, sky plot labels
    Controls:
    - Auto-track toggle in pass list header (syncs with station.conf)
    - Stop button stops tracking AND parks antenna (clean exit)
    - Track button: stops current, starts new, immediate state bar feedback
    - Station.py always parks after pass completion or stop
    Sky plot:
    - Satellite names shown for first 5 passes (positioned to avoid overlap)
    - Distinct colors per trajectory from SKY_COLORS palette
    - Labels use trajectory color, positioned radially from AOS point
    - Reduced canvas heights (240/280/340px) for better proportions
    Station.py:
    - Manual track requests allow joining mid-pass (auto skips >20%)
    - Checks for new trac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
    [dashboard.py, station.py]
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2026-03-18 Fix stop actually stopping — pause flag, auto-track off on stop
    When user presses Stop:
    - Dashboard disables auto-track and updates toggle UI
    - station.py writes ~/.station_paused flag on stop
    - Daemon loop checks pause flag before each pass:
    - If paused + auto off → stays idle (no auto-start)
    - If paused + manual track request → resumes with that satellite
    - If paused + auto re-enabled → clears pause and continues
    - Auto mode skips first 10% of pass (was 20%) — horizon clearance
    - Manual track always allows mid-pass join
    [station.py]
2026-03-18 Add AMSAT as primary TLE source (CelesTrak 403 workaround)
    CelesTrak started returning HTTP 403 for automated TLE requests.
    Added AMSAT (amsat.org/tle/current/nasabare.txt) as the primary
    TLE source — reliable, no rate limiting. CelesTrak URLs kept as
    fallback in case AMSAT is unreachable.
    [dashboard.py, station.py]
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2026-03-18 Add satellite filters, transmitter enrichment, fix GPU/RAM usage
    Satellite enrichment:
    - Fetches 2656 transmitters from SatNOGS DB API (cached 2h)
    - Passes enriched with freq_mhz, mode, baud, band, cc1200_ok
    - Pass list shows frequency and modulation for each satellite
    - Filter panel: All/UHF/VHF/CC1200/RTL-SDR chip buttons
    - Filter applied to pass list rendering (sky plot shows all)
    Performance fixes:
    - Removed Vanta.js 3D globe (Three.js + WebGL GPU hog)
    - Removed Three.js and Vanta.js CDN script loads
    - Sky plot throttled to 4fps (was 60fps via RAF)
    - CSS star background retained as visual backdrop
    - Transmitter data now enriched at read time, not compute time
    (fixes empty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
    [dashboard.py]
2026-03-18 Fix manual tracking, add hover-to-highlight, responsive track requests
    Manual tracking fix:
    - station.py now re-reads station.conf inside the pass iteration loop
    - Manual track requests honored even when auto_track is off
    - Track request checked every 3s during sleep (was 300s wait)
    - Cleared after reading so it doesn't repeat
    Hover-to-highlight:
    - Hovering a pass in the sidebar highlights its trajectory on sky plot
    - All other trajectories dim to 20% opacity during hover
    - Dots and labels hidden for dimmed passes
    - Hovered trajectory drawn at 3.0px width in full color
    - mouseenter/mouseleave events on pass items
    [station.py]
2026-03-18 Fix tracking, add SatNOGS DB TLEs (1500+ sats), expand filters
    Tracking reliability:
    - Track requests use ~/.station_track file (simple, reliable)
    - Stop/pause flags cleared when tracking starts
    - station.py checks track file every 3s during sleep
    - No more race conditions with station.conf read/write/clear
    More satellites:
    - Added SatNOGS DB TLE API as primary source (1500+ satellites)
    - AMSAT + CelesTrak as secondary sources
    - max_passes increased from 10 to 50
    Filter panel expanded:
    - Frequency: All / 430-440 MHz / VHF
    - Receiver: CC1200 / SDR only
    - Quality: High pass (>45°) / Medium (>20°)
    Performance:
    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
    [dashboard.py, station.py]
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2026-03-18 Fix TLE name prefix, tracking state feedback, hover gaps, receivable filter
    TLE fix:
    - SatNOGS DB tle0 field starts with "0 " — now stripped
    - Satellite names display correctly (no more "0 CARBONITE 1")
    Tracking UX:
    - _pendingTrack variable persists "Waiting: X" state until tracking starts
    - State bar shows "Waiting" with amber indicator after pressing Track
    - Stop button visible during pending track
    - Pending track cleared once actual tracking begins
    - Items overlap by -1px to eliminate hover gap flicker
    - Default filter: UHF (433) — only show receivable satellites
    - Backend pre-filters to receivable frequencies before computation
    Receivable satellite filter:
    - Only comput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
    [dashboard.py]
2026-03-18 Fix Pi RAM usage: only cache UHF/VHF satellites and transmitters
    Was loading all 1500+ satellites and 2656 transmitters into memory,
    using 375/416 MB RAM and causing Pi 3A+ to swap/timeout.
    Now:
    - TLE fetch: only keeps satellites with UHF (430-440) or VHF (130-175) transmitters
    - Transmitter cache: only stores UHF/VHF entries
    - Explicit del of JSON data after parsing to free memory immediately
    - Reduces from ~1500 to ~382 satellites computed
    - Peak RAM: ~197 MB (was 375 MB)
    [dashboard.py]
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2026-03-18 Fix tracking reliability: TLE cache, AOS wait stop, forEach bug
    TLE caching in station.py:
    - TLEs cached for 30 min (was fetched fresh every cycle: 47s)
    - Second Track click is now instant instead of waiting for refetch
    AOS wait loop:
    - Now checks for stop file and new track requests every 3s
    - Can abort 66-minute AOS wait instantly when user presses Stop
    - New track request during AOS wait aborts current and re-enters
    Dashboard fixes:
    - forEach uses return not continue (JS syntax bug)
    - _pendingTrack cleared on Stop
    - Pass items: 0 gap, larger padding (fixes hover flicker)
    - setup_complete flag handled in station.conf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
    [station.py]
2026-03-18 Stability: 2h prediction window, 15min refresh, always show antenna
    Memory optimization:
    - Prediction window reduced from 12h to 2h (fewer passes computed)
    - Recompute interval increased from 60s to 15min
    - station.py uses only AMSAT TLEs (~80 sats, not 1500)
    - Peak RAM: 279MB (was 375MB)
    - Antenna position (cyan dot + ANT label) ALWAYS shown when connected
    - Pending track: target trajectory in amber, all others dimmed
    - Tracking: only active trajectory shown
    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
    [dashboard.py, station.py]
2026-03-18 Fix case-insensitive tracking, rotctld reconnect, sky plot pending
    Tracking name mismatch:
    - TLE sources use different casing ("TEN-KOH" vs "Ten-Koh")
    - _pendingTrack cleared with case-insensitive substring match
    - Sky plot isPendingTarget comparison now case-insensitive
    - Pending track: completely hides all other trajectories (was dim)
    Rotctld connection:
    - _rotctl_cmd retries once on connection failure (auto-reconnect)
    - Fixes AZ/EL showing 0.0/0.0 when connection drops mid-session
    [dashboard.py]
2026-03-18 Critical RAM fix: smaller batches, fewer points, gc.collect()
    The Pi 3A+ (416MB) was crashing during pass computation.
    - Trajectory points: 20 → 10 (halves memory per pass)
    - Batch size: 100 → 50 (lower peak allocation)
    - Max passes cached: 50 → 25
    - gc.collect() between batches and after completion
    - Total RAM reduction: ~40% less peak usage
    [dashboard.py]
2026-03-18 Fix Pi crash: 1 pass per sat, 2s timeout, UHF-only filter
    Root cause: PyEphem next_pass() hangs on deep space / HEO satellites,
    causing the batch loop to freeze at "200/382" and RAM to climb until
    the Pi OOM-kills everything.
    Fixes:
    - Only 1 pass computed per satellite (was unlimited in 2h window)
    - 2 second timeout per satellite computation (skips stuck ones)
    - Pre-filter restricted to UHF 430-440 MHz only (was UHF+VHF)
    - This reduces from ~382 to ~200 computable satellites
    - Combined with batch_size=50, n_points=10, gc.collect() between
    Expected peak RAM: ~220MB (was 335MB)
    [dashboard.py]
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2026-03-18 Fix header AZ, dedup satellites, include tracked sat in pass list
    Header AZ: normalize negative values to 0-360 (was showing -275°)
    Dedup: remove duplicate satellites from different TLE sources
    (TECHNOSAT vs TechnoSat, LILACSAT 2 vs LILACSAT-2)
    Tracked sat: always include currently-tracked satellite in pass API
    response, even if not in computed pass cache
    [dashboard.py]
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2026-03-18 Fix sky plot crash, loading speed, remove stub satellite entries
    - Spline code wrapped in try/catch with lineTo fallback
    - Fixes blank sky plot when bezierCurveTo receives bad coordinates
    - pts.length >= 2 check (was > 0 which still tried with 1 point)
    Loading screen:
    - Reduced from 2.5s to 1.5s minimum display time
    Stub satellite removal:
    - Removed fake pass entries for tracked satellites not in cache
    - These had max_el=0, trajectory=[], duration=900s — all wrong
    - Frontend handles missing satellites via status API rf.satellite
    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
    [dashboard.py]
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2026-03-18 Add restart button, tighter hover threshold, expose doRestart
    Restart:
    - POST /api/restart → parks antenna then sudo reboot
    - Settings page: Restart button (accent) above Shutdown (amber)
    - Shows spinner + "Restarting" screen, auto-reloads after 60s
    Hover fix:
    - Canvas hover threshold tightened from 30px to 15px
    - Reduces false-positive trajectory highlighting
    ANT dot:
    - Already shows when connected (verified code)
    - Sky plot redraws on every status poll (_skyNeedsRedraw = true)
    - Position updates within 1 second of jog command
    [dashboard.py]
2026-03-19 Focus mode, live telemetry, trajectory stability, mobile layout
    Dashboard:
    - Focus mode: left panel slides to telemetry view during tracking
    (range, Doppler, pointing error, link margin, RSSI sparkline,
    pass geometry). Auto-enters on track, exits on LOS/stop.
    - Live trajectory fallback: builds sky plot arc from cmd_az/cmd_el
    when pass data unavailable (survives cache rebuilds).
    - Color-coded pass dots: orange=overhead, green=<5min, grey=upcoming
    - Server-side expired pass filtering + NORAD ID dedup
    - Recent Passes panel (last 20 tracked passes)
    - 4Hz rotator polling + CSS compass interpolation for smooth movement
    - Client-side UTC clock (independent of station.py)
    - Pass banner hidden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
    [dashboard.py, station.py]
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2026-03-19 Fix OOM: reduce polling from 4Hz to 2Hz
    4Hz polling (0.25s) caused OOM killer on Pi 3A+ (416MB RAM).
    Each poll does rotctld TCP, file I/O, system stats — too much at 4x/s.
    Reduced to 2Hz (0.5s) which is still smooth with CSS transitions.
    [dashboard.py]
2026-03-19 Fix crash loop: SO_REUSEADDR + reduce polling to 2Hz
    - Add SO_REUSEADDR to prevent "Address already in use" on restart
    - 4Hz polling caused OOM on Pi 3A+ (416MB), reduced to 2Hz
    - Systemd services: StartLimitIntervalSec=0 (no restart rate limit)
    - RestartSec=5/10 for dashboard/station (give Pi time to free memory)
    [dashboard.py]
2026-03-19 Resilience: handle rotctld disconnect, fast SIGTERM, park retry
    station.py:
    - Catch BrokenPipeError in tracking loop, auto-reconnect to rotctld
    - Retry park with reconnect in finally block (handles rotctld restart)
    - Prevents daemon crash on USB disconnect during tracking
    dashboard.py:
    - Fast SIGTERM handler: os._exit(0) instead of server.shutdown()
    (avoids 5s timeout when polling thread blocks on network I/O)
    - Prevents "Address already in use" on restart after SIGKILL
    dashboard.html:
    - Clear _selectedPass on LOS (prevents greyed-out pass list)
    - SAT marker only draws when _isTracking (no phantom markers when idle)
    [dashboard.py, station.py]
2026-04-04 MOTOR_RF_HAT: initial project setup — combined motor control + RF HAT
    New KiCad project merging MotorPCB and RF_HAT into a single Pi HAT board.
    Single RP2040 Pico handles motor control (2x A4950 H-bridge), dual CC1200
    (UHF+VHF), ADXL345 IMU, NeoPixel, and buzzer over one UART to Pi.
    Contents:
    - Local symbol library: A4950E, ADXL345, XT30PW-M, JST-XH 2/6-pin,
    plus MotorPCB components (pads, buttons, resistors)
    - Local footprints: SOIC-8-EP (A4950), LGA-14 (ADXL345), JST-XH 2/4/6-pin,
    beeper, WS2812B, XT30, plus MotorPCB footprints and 3D models
    - Datasheets: A4950, ADXL345, LMR51420, CC1200, CC120x userguide,
    CC1120EM reference designs, TB6642FG/TPS560430 (reference)
    - Reference sche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
    [CC1200_UHF_432MHz.kicad_sch, CC1200_VHF_144MHz.kicad_sch, Pi_Header.kicad_sch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]
2026-04-04 MOTOR_RF_HAT: clean project — KiCad 10 ready, all libs local
    - Created MOTOR_RF_HAT.kicad_pro + empty MOTOR_RF_HAT.kicad_sch (A3, title block set)
    - sym-lib-table + fp-lib-table using ${KIPRJMOD} relative paths
    - Cleaned symbol lib: kept A4950E, ADXL345, XT30PW-M, JST-XH 2/6-pin only
    - All footprint refs point to components: prefix (verified resolving)
    - Removed unused MotorPCB footprints (buttons, flash, fuse, USB-C, QFN, R0402)
    - Moved 3D models from components.pretty/ to components.3dshapes/
    - Added XT30PW-M footprint + STEP model (was in JLC2KiCad_lib subdir)
    - Removed JLC2KiCad_lib tool repo that was accidentally copied
    - ERC: 0 errors, 0 warnings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
    [MOTOR_RF_HAT.kicad_sch]
2026-04-04 MOTOR_RF_HAT: port full RF_HAT project with all libs localized
    Copied complete RF_HAT_out KiCad project (schematic + PCB layout +
    4 hierarchical sub-sheets) as the base for the combined board.
    Changes from original RF_HAT:
    - Renamed RF_HAT → MOTOR_RF_HAT in all project/schematic references
    - Imported LMR51420YDDCR + XRTC303020D4R7MBCA symbols from personal
    lib into project-local components.kicad_sym
    - Copied corresponding footprints + 3D models (SOT-23-6, inductor)
    into components.pretty/ and components.3dshapes/
    - Fixed all lib: → components: references in schematics and PCB
    - Removed reference/ directory (schematics are now live sub-sheets)
    - ERC: 20 violations (19 pre-existing fr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
    [CC1200_UHF_432MHz.kicad_sch, CC1200_VHF_144MHz.kicad_sch, MOTOR_RF_HAT.kicad_pcb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]
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2026-04-04 MOTOR_RF_HAT: import MotorPCB sub-sheets + fix lib version
    Imported azimuth, elevation, encoders, gyro, solder_pads sub-sheets
    from MotorPCB. Fixed project references (motorPCB → MOTOR_RF_HAT)
    and footprint prefixes (footprint: → components:).
    Motor connectors use 6-pin JST-XH (S6B-XH-A) carrying motor power +
    encoder signals on one connector, same as MotorPCB.
    Reverted components.kicad_sym version to 20241209 (KiCad 9 format)
    for compatibility — KiCad 10 reads it fine.
    Sub-sheets still reference easyeda2kicad:TB6642FG for motor drivers —
    these will be manually replaced with components:A4950E in KiCad.
    To add sub-sheets: Place → Hierarchical Sheet, point to the .kicad_sch
    files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
    [azimuth.kicad_sch, elevation.kicad_sch, encoders.kicad_sch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]
2026-04-04 MOTOR_RF_HAT: link MotorPCB sub-sheets as hierarchical sheets
    Added Encoders, Azimuth, Elevation, Gyro, and Solder_Pads as
    hierarchical sheets in the root schematic. All sub-sheet files
    are the actual MotorPCB originals with project refs updated.
    Root schematic now has 9 sub-sheets:
    - Pico_SPI_Host (from RF_HAT)
    - CC1200_UHF_432MHz (from RF_HAT)
    - CC1200_VHF_144MHz (from RF_HAT)
    - Pi_Header (from RF_HAT)
    - Encoders (from MotorPCB — 6-pin JST with motor + encoder)
    - Azimuth (from MotorPCB — TB6642FG, to be replaced with A4950E)
    - Elevation (from MotorPCB — TB6642FG, to be replaced with A4950E)
    - Gyro (from MotorPCB — ADXL345 via solder pads)
    - Solder_Pads (from MotorPCB — test poin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
    [MOTOR_RF_HAT.kicad_sch]
2026-04-04 MOTOR_RF_HAT: localize all libraries — zero external dependencies
    - Extracted smallpad footprint from MotorPCB PCB into local lib
    - Extracted TB6642FG (HSOP-16) footprint from MotorPCB PCB into local lib
    - Extracted TB6642FG_8_EL symbol from MotorPCB schematic into local lib
    - Fixed all references: TestPoint:smallpad → components:smallpad,
    easyeda2kicad:TB6642FG → components:TB6642FG_8_EL,
    easyeda2kicad:HSOP-16 → components:HSOP-16
    All schematic lib_id references now resolve to either:
    - components: (project-local)
    - KiCad globals (Device, Connector, RF, power, etc.)
    Local lib now contains 7 symbols:
    S2B-XH-A-(LF)(SN), S6B-XH-A_(LF)(SN), XT30PW-M, A4950E,
    LMR51420YDDCR,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
    [azimuth.kicad_sch, elevation.kicad_sch, solder_pads.kicad_sch]
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2026-04-04 MOTOR_RF_HAT: fix TestPoint:smallpad → components:smallpad in solder_pads
    All 18 test point footprint references in solder_pads.kicad_sch now
    point to the local components:smallpad instead of TestPoint:smallpad
    (which doesn't exist in KiCad's global TestPoint library).
    [MOTOR_RF_HAT.kicad_sch, azimuth.kicad_sch, elevation.kicad_sch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]
2026-04-04 MOTOR_RF_HAT: add TestPoint lib alias to fix persistent smallpad errors
    KiCad's lib_symbols cache keeps reverting footprint refs to
    TestPoint:smallpad on save. Added TestPoint as a footprint library
    alias pointing to components.pretty so both TestPoint:smallpad and
    components:smallpad resolve to the same local footprint.
    [CC1200_UHF_432MHz.kicad_sch, CC1200_VHF_144MHz.kicad_sch, MOTOR_RF_HAT.kicad_pcb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]
2026-04-04 MOTOR_RF_HAT: 0805→0603 passives, encoder caps 100nF→100pF
    - Changed all capacitor and resistor footprints from 0805 to 0603
    across all schematic sheets (CC1200 UHF/VHF, root, azimuth,
    elevation, encoders)
    - Fixed encoder RC filter caps C68-C71 from 100nF to 100pF
    (fc = 15.9 MHz, transparent to 35 kHz encoder signal)
    [CC1200_UHF_432MHz.kicad_sch, CC1200_VHF_144MHz.kicad_sch, MOTOR_RF_HAT.kicad_sch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]
2026-04-04 MOTOR_RF_HAT: fix cap packages — 10uF/50V, 22uF, 4.7uF/50V back to 0805
    These values cannot physically fit in 0603:
    - C1 (4.7uF 50V): 0603→0805
    - C3 (22uF): 0603→0805
    - C60-C62 (10uF AZ motor VBB bypass): 0603→0805
    - C64-C66 (10uF EL motor VBB bypass): 0603→0805
    All other passives remain 0603.
    [MOTOR_RF_HAT.kicad_pcb, MOTOR_RF_HAT.kicad_sch, azimuth.kicad_sch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]
2026-04-04 MOTOR_RF_HAT: BOM enrichment + design review fixes + firmware scaffold
    BOM enrichment:
    - Added LCSC, MPN, and Farnell properties to 122 of 131 components
    across all schematic sheets (remaining 9 are mechanical/test fixtures)
    - Sourced all passives (0603 caps/resistors/inductors), ICs (CC1200,
    A4950E, LMR51420, BSS138, WS2812B), connectors (JST-XH, XT30, SMA)
    Design review fixes:
    - C1 (4.7uF 50V): 0805→1206 (physically impossible in 0805)
    - R1/R2: fixed footprint library from Capacitor_SMD to Resistor_SMD
    Firmware scaffold (Firmware/rp2040-motor-rf-hat/):
    - Complete merged firmware: RF HAT base + rotator motor control
    - motor_pwm.cpp refactored for 2-pin A4950 (IN1/IN2, no PWM pin)
    -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
    [MOTOR_RF_HAT.kicad_sch, Pico_SPI_Host.kicad_sch, azimuth.kicad_sch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]
2026-04-04 MOTOR_RF_HAT: fix all 3D model paths in footprints and PCB
    Fixed 3D model references in local footprints:
    - JST 2/6-pin: components.pretty → components.3dshapes
    - XT30PW-M: packages3d/ → ${KIPRJMOD}/components.3dshapes/
    - SOT-23-6 (LMR51420): lib.3dshapes → components.3dshapes
    - Inductor: lib.3dshapes → components.3dshapes
    - Beeper: components.pretty → components.3dshapes
    - HSOP-16: ${EASYEDA2KICAD} → components.3dshapes
    Also fixed same paths in MOTOR_RF_HAT.kicad_pcb.
    A4950 (SOIC-8-EP) and JST-XH 4-pin use KiCad global 3D models
    which resolve correctly via ${KICAD10_3DMODEL_DIR}.
    WS2812B-2020 has no 3D model (cosmetic only, not blocking).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
    [MOTOR_RF_HAT.kicad_pcb]
2026-04-04 MOTOR_RF_HAT: fix all 3D models — KICAD9→KICAD10, Pi header 2x20
    - Replaced all KICAD9_3DMODEL_DIR → KICAD10_3DMODEL_DIR in PCB file
    (98 references) and local footprints. KiCad 10 uses KICAD10_ prefix.
    - Fixed Pi header J3: 3D model was PinHeader_2x10 → PinHeader_2x20
    - Fixed .wrl → .step for SOT-23-6 and inductor in PCB file
    - All 121 3D model references now use KICAD10_3DMODEL_DIR or
    ${KIPRJMOD}/components.3dshapes/ — verified all files exist on disk
    [MOTOR_RF_HAT.kicad_pcb]
2026-04-04 MOTOR_RF_HAT: fix XT30, A4950, WS2812B 3D models
    These three didn't exist in KiCad 10's global 3D library:
    - XT30PW-M: global lib missing → use local components.3dshapes/
    - SOIC-8-1EP (A4950): EP2.41x3.3mm missing → use EP2.41x3.81mm (closest)
    - WS2812B-2020: not in KiCad 10 → use local WS2812B_2020.stp
    [MOTOR_RF_HAT.kicad_pcb]
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
